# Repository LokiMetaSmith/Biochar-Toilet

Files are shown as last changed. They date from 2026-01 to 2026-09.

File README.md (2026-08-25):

# Current Status

Phase 1 (conductive heating prototype) is complete. All experiment data, firmware, schematics, PCB design files, and progress reports are in the [`Conductive Heating Prototype/`](https://github.com/PubInv/Biochar-Toilet/tree/main/Project%20Files/Conductive%20Heating%20Prototype) folder.

We're now in Phase 2: induction heating using a magnetite matrix. The shift from resistive heating matters because induction generates heat directly inside the charring cup — no exposed coils corroding in the process environment, and faster energy delivery to the material itself.

Ongoing experiment logs are in the [Progress Reports](https://github.com/PubInv/Biochar-Toilet/blob/main/Project%20Files/Progress%20Reports.md). Dedicated firmware for the dual-induction prototype is located in [`Project Files/Induction Heating Prototype/Firmware`](https://github.com/PubInv/Biochar-Toilet/tree/main/Project%20Files/Induction%20Heating%20Prototype/Firmware).

Screenshot 2025-11-21 at 6 10 39 PM

---

# Biochar Toilet

A reliable toilet that could quickly reduce human fecal matter to completely sanitary biochar would make the poorest people of the
Earth healthier. In many communities, Western-style sewage systems would be very expensive and impractical due to
geology, the lack of density in farming communities made of small land holdings, a lack of capital, and a lack of
social and political organization to dig trenches and lay pipes efficiently.

Reducing a typical human stool to biochar requires an energy input of about 600 kilojoules (see detailed analysis in referenced spreadsheet).
Even for the poorest people, the cost of this electricity is quite low---less than one US cent $0.01USD. One kilowatt hour is 3.6 MJ (megajoules).
Expensive electrical power around the world is $0.45/kWh is $0.075 USD--or less than eight cents. Even if our toilet is inefficient, it
seems possible to make a toilet whose operating cost is affordable for the poorest people, at $27.375 per year (this cost does not include
the capital costs of the toilet).

Biochar can be used as a fuel or a garden amendment. Note, however, that human stools are so small (128 grams nominally) that this is not a meaningful approach for carbon sequestration.

# Initial Design Idea

The problem of toilets is a widely researched area. Our approach may be slightly novel. We start from some assumptions:

1. Electricity is an input.
2. Complete biological safety of the end product is required.
3. We choose to temporarily ignore the capital costs of the toilet in our research.
4. Because we have to char in the absence of oxygen to prevent combustion, we can assume that we need an air-tight or pressure controlled reaction vessel.
5. A major problem in charring is to first dry the sample, and drying is primarily a problem of water transport.

We therefore conclude that our basic design will be a sealed reaction vessel with a valve that allows steam to be transported out
of the reaction chamber. We will heat the chamber contents until a desired pressure is created and then transport the water
vapor away by opening the valve. The valve will be controlled so as to avoid most gases (air) from entering the chamber.
Opening the valve will "flash" the water in the sample into steam, which will have the desirable properties of being
extremely murderous to any organisms present in the sample, and physically destructive to both plant and animal cells.
It may even physically disrupt the sample, which could be advantageous.

When the sample is sufficiently dry, we will heat it to charring temperature. When the sample is fully charred, and then cooled
and possibly wetted to avoid spontaneous combustion, the operator will be alerted that the sample is safe to remove and either combust or use as a garden amendment.

# Energy Analysis

Volunteer Nupur Bhalla working with Invention Coach Robert L. Read has produced a [Google Sheet](https://docs.google.com/spreadsheets/d/1ZwIqP0B2wM6QrpZTNiK1hNnNmIEIal7qxYdgEJz8Iog/edit?usp=sharing) representing an energy analysis of the drying and heating process.

# Heating Mechanisms

Since we will have a sealed metal reaction vessel, radio frequency (RF) heating is a possibility.
However, it is expected to become less effective as the sample dries.
We therefore intend to explore the possibility of using simple Joule resistive heating of a stainless steel vessel directly.
RF heating, however, has the advantage of heating the sample volumetrically (not requiring conduction), which may be a tremendous advantage.

# Phase 1: Conductive Heating Prototype (Complete)

Phase 1 used a pressure cooker as the reaction vessel, a hot plate controlled by an SSR, and an ESP32-based sensing system. The goal was to confirm the core architecture before committing to higher-temperature methods.

It worked. When pressure drops below ~1 PSI while temperature keeps climbing, the system correctly identifies the dry state and cuts heater power automatically. Flash decompression also checked out — opening the solenoid under pressure causes trapped water to flash to steam. A bread charring test (~110°C, 2h40m) produced a visibly charred loaf, though the dryness algorithm didn't trigger since the bread's low moisture content didn't produce a distinct enough pressure change during drying. Soot accumulation on the lid also flagged particulate management as something to design for in future iterations.

The hard limit we hit: full charring temperatures aren't safe inside a standard pressure cooker. Lawrence Kincheloe suggested placing an inner cup (heated by a silicon nitride igniter) inside the vessel so the outer shell stays cool — that idea feeds directly into Phase 2.

We also designed a custom control PCB for this phase (ESP32-H2, v0.3.0) with dual MOSFET valve drivers, dual SSR outputs, a pressure ADC, and a MAX31855 thermocouple interface. Everything is in the [`Conductive Heating Prototype/`](https://github.com/PubInv/Biochar-Toilet/tree/main/Project%20Files/Conductive%20Heating%20Prototype) folder.

# Phase 2: Induction System Development (In Progress)

We've switched from resistive heating to pulsed induction using a magnetite matrix. The magnetite sits inside the charring cup and converts the induction field directly into heat — no exposed coils, no conduction losses through the vessel wall.

Dedicated dual-induction firmware and specifications are documented in [`Project Files/Induction Heating Prototype/README.md`](https://github.com/PubInv/Biochar-Toilet/blob/main/Project%20Files/Induction%20Heating%20Prototype/README.md).

Early results from Lawrence Kincheloe and Peter are encouraging. Five grams of magnetite reached 740°F in 60 seconds; the same mass of carbon steel bearings only hit 130°F. Volume-matching the steel to the magnetite closes the gap considerably (~940°F peak), which suggests surface area and density matter more than material choice at this scale. They also charred cheese puffs at 833°F over 16 minutes in open air, with residue on the crucible cap showing evidence of partial pyrolysis.

Full experiment logs are in the [Progress Reports](https://github.com/PubInv/Biochar-Toilet/blob/main/Project%20Files/Progress%20Reports.md).

# Research Plans

The next step is pushing the induction system to actual charring temperatures — hot enough to produce biochar from organic material comparable to human stool. Work on coil geometry and magnetic field focusing is ongoing in parallel with fabrication.

Basic Biochar Toilet Design (https://github.com/user-attachments/assets/ea41856b-7663-43a1-bf12-8a3a2311aef8) 

# References

"An Experimental 13.56 MHz Radio Frequency Heating System
for Efficient Thermal Pretreatment of Wastewater Sludge",
Md. S. Ferdous, Ehssan H. Koupaie, Cigdem Eskicioglu, and Thomas Johnson*

# Volunteer Opportunities

This project is still active. If you have a background in mechanical engineering, heat engineering, or chemistry, we'd be glad to hear from you.

Reach out to Inventor Coach [Robert L. Read](https://github.com/PubInv/Biochar-Toilet/blob/main/read.robert@gmail.com) or Volunteer Coordinator [Miriam Castillo](https://www.linkedin.com/in/cstllgtrrz/). More at the [Volunteer Page](https://www.pubinv.org/volunteer/).

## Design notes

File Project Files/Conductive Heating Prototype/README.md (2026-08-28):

# Conductive Heating Prototype — Phase 1

**Biochar Toilet Project | Phase 1 Documentation** |
**Contributor:** Hardhik Pyla ([@hardhik03](https://github.com/hardhik03)) |
**Period:** November 2025 – May 2026 |
**Status:** Complete

---

## Overview

Phase 1 of the Biochar Toilet project was a proof-of-concept prototype to validate the core system architecture before advancing to higher-temperature charring methods. The goal was to build the smallest, safest system possible — one that could demonstrate:

1. Reliable pressure and temperature sensing inside a sealed reaction vessel
2. Automatic dryness detection using temperature–pressure divergence logic
3. Autonomous heater shutoff via SSR when the dry state is detected
4. Flash decompression: opening a solenoid valve under pressure to flash-boil trapped water into steam (providing mechanical sterility)

The reaction vessel was a standard pressure cooker. The heating source was a hot plate controlled by a solid-state relay (SSR). Sensing and control were handled by an ESP32-based embedded system, later migrated to a custom-designed control PCB.

---

## System Architecture

```
[Pressure Cooker] ──── [K-type Thermocouple] ───► [ESP32-H2 Control Board]
      │                                                      │
      ├──── [Analog Pressure Sensor] ───────────────────────►│
      │                                                      │
      └──── [Solenoid Valve 1] ◄──── [MOSFET Driver] ◄──────┤
                                                             │
[Hot Plate] ◄──── [SSR 1] ◄──── [NPN BJT Driver] ◄──────────┘
```

**Dryness Detection Logic:**
When pressure drops below ~1 PSI and stays there for 15 seconds (after an initial active cycle above 2 PSI), the system latches the "dry" flag and disables the heater SSR. This is based on the observed behavior that temperature rises sharply while pressure stays low once all moisture has been driven off.

**Valve Control Logic:**
The solenoid valve opens when pressure reaches 8 PSI and closes at 7 PSI (hysteresis band), releasing steam to the condenser/containment vessel.

**Temperature Control:**
A proportional controller (Kp = 0.03) targets 200°C with a 2-second PWM window. An exponential moving average (α = 0.10) smooths thermocouple readings.

---

## Hardware

| Component | Description |
|---|---|
| Reaction vessel | Standard pressure cooker |
| Microcontroller | ESP32 (breadboard) → ESP32-H2 DEVKITM-1-N4 (custom PCB) |
| Temperature sensor | K-type thermocouple + MAX31855 breakout (SPI) |
| Pressure sensor | Analog 0–100 PSI, read via ADC with voltage divider (0–5V → 0–3.3V) |
| Solenoid valve | 12V solenoid, driven by IRLB3813PBF N-channel MOSFET |
| Heater control | Solid-state relay (SSR 1), NPN BJT driver — active HIGH |
| Hot plate | External AC hot plate, switched via SSR |
| Custom PCB | Bio-Char Control Board v0.1.0 (KiCad 9, 2-layer FR4, ~$48 BOM) |

---

## Pin Configuration

The table below reflects the **working firmware pin assignments** as validated during PCB bring-up. These differ from the original KiCad schematic assignments — see the [Pin Change Notes](#pin-change-notes) section below.

| GPIO | Function | Direction | Notes |
|---|---|---|---|
| GPIO0 | MAX31855 CLK | Output | SPI clock |
| GPIO1 | MAX31855 CS | Output | SPI chip select |
| GPIO2 | MAX31855 DO | Input | SPI MISO — read-only, no MOSI needed |
| GPIO3 | Pressure Sensor ADC | Input | ADC1_CH3, 0–100 PSI via voltage divider |
| GPIO4 | SSR 1 / Heater | Output | **Active HIGH** — drives NPN BJT base to complete SSR circuit |
| GPIO5 | SSR 2 | Output | Reserved — not currently active (see firmware comments) |
| GPIO10 | Solenoid Valve 1 | Output | MOSFET (IRLB3813PBF) driven |
| GPIO11 | Solenoid Valve 2 | Output | Reserved — not currently active (see firmware comments) |

### Pin Change Notes

During PCB bring-up, the SSR control pins had to be remapped due to a conflict with the ESP32-H2's internal crystal peripheral:

- **GPIO13 and GPIO14** are internally tied to the ESP32-H2's 32 kHz RTC crystal oscillator. The original schematic routed SSR1 and SSR2 control lines to these pins. On Test 1 (05/06/2026), both SSR outputs were unresponsive — the GPIOs could not be driven as outputs while the crystal is active.
- As a Test 1 workaround, SSR1 and SSR2 were manually driven from **GPIO4 and GPIO5** (open pins on the board), confirming the BJT and SSR circuitry was otherwise functional.
- On 05/14/2026, the GPIO13 and GPIO14 traces were physically cut and jumper wires were soldered from GPIO4 → SSR1 and GPIO5 → SSR2 pads. This hardware rework makes the board match the firmware pin assignments permanently.
- The corrected routing will be incorporated into the next PCB design revision.

### Heater/SSR Logic Change

The original Arduino firmware used **active LOW** logic for the heater (GPIO4 LOW = SSR ON, sinking to GND via the SSR's internal optocoupler). The PCB design introduced an NPN BJT between the ESP32 GPIO and the SSR input, which inverts the signal:

```
GPIO4 HIGH → BJT base HIGH → collector pulls SSR input → SSR ON
GPIO4 LOW  → BJT OFF       → SSR input floating        → SSR OFF
```

The ESP-IDF firmware (`Firmware/main/main.c`) uses **active HIGH** accordingly. The `set_heater()` function drives GPIO4 HIGH to turn the heater on and LOW to turn it off.

---

## Known Errors and Issues

| # | Issue | Status | Notes |
|---|---|---|---|
| 1 | ADC non-linearity at low raw values (<350) | Mitigated | Readings below ~0.5 PSI fluctuate. DRY_PRESSURE_MAX threshold (1.0 PSI) provides sufficient headroom for reliable detection. |
| 2 | MAX31855 returns NaN on first read after power-on | Handled | ~100ms settling time required. EMA initialisation stays NaN until a valid reading arrives — no false triggers. |
| 3 | GPIO3 shared with JTAG MTDI | Known | Disconnect JTAG debugger before running in production, or remap ADC to GPIO4/5 if debugging under sustained load. |
| 4 | GPIO13/GPIO14 RTC crystal conflict — SSR pins non-functional | Resolved (05/14/2026) | Original schematic routed SSR1/SSR2 to GPIO13/GPIO14, which are internally tied to the 32 kHz RTC crystal on the ESP32-H2. Confirmed on Test 1 (05/06): both SSR outputs were unresponsive. Test 1 workaround: SSR driven manually from GPIO4/GPIO5. Permanent fix: traces to GPIO13/GPIO14 cut and jumper wires soldered to GPIO4/GPIO5 pads. Next PCB revision will correct the routing. |
| 5 | D2/D5 diode voltage drop — solenoid safety switches not opening | Resolved (05/14/2026) | 1N4148 diodes on the solenoid valve safety switch circuits had a forward voltage drop high enough to prevent the gate logic from pulling low cleanly, blocking valve operation. Bypassing the diodes confirmed the MOSFET/solenoid path was functional. D2 and D5 replaced with 1N4001 diodes; valve operation re-verified successfully. |
| 6 | Bread charring — dryness detection did not trigger | Investigated | Bread had insufficient initial moisture to produce a distinct pressure signature during drying. Detection heuristic works correctly for water-heavy samples. |

---

## Experiment Timeline

See [`Progress Reports.md`](https://github.com/PubInv/Biochar-Toilet/blob/main/Project%20Files/Progress%20Reports.md) for full dated entries. Summary:

| Date | Milestone |
|---|---|
| Nov 21, 2025 | Pressure sensor schematic designed |
| Dec 5, 2025 | Initial pressure sensor physical calibration and error testing |
| Dec 11, 2025 | Dryness detection breadboard prototype — valve, pressure, dryness logic validated |
| Jan 16, 2026 | Microcontroller + solenoid valve + SSR hardware integration |
| Feb 13, 2026 | Bread charring test with auto-shutoff — end-to-end system validated |
| Mar 5–18, 2026 | Custom Control Board PCB design (v0.1.0) — Gerbers generated |
| May 6, 2026 | PCB Board Test 1 — PSI and dry detection verified; GPIO13/14 crystal conflict and D2/D5 diode drop identified |
| May 14, 2026 | Hardware rework — GPIO13/14 traces cut, SSR lines jumpered to GPIO4/5; D2/D5 replaced with 1N4001; valve operation re-verified |

---

## Key Results

**Dryness Detection:** Successfully confirmed. When pressure falls below 1 PSI for 15 sustained seconds following an active cycle, the system correctly identifies the dry state and disables the heater.

**Flash Decompression:** Validated. Opening the solenoid valve under pressure causes water to flash to steam. However, at ~15 PSI, the valve restriction prevented instantaneous pressure drop — steam flowed continuously rather than flashing off in a single burst.

**Bread Charring Test (Feb 13, 2026):** A loaf of bread was heated inside the sealed pressure cooker at ~110°C for approximately 2 hours and 40 minutes. The loaf was visibly charred. The dryness detection algorithm did not trigger in this run (see Known Errors #5). Soot accumulation on the chamber lid was observed, raising particulate management as a future design concern.

**Key Finding — Safety Limit:** Full charring temperatures cannot be safely reached inside the pressure cooker vessel. Lawrence Kincheloe proposed an inner charring cup (heated by a silicon nitride igniter) inside the pressure cooker, keeping the outer vessel cool. This informed the transition to Phase 2 (induction heating).

---

## Firmware

Two firmware versions exist for this prototype:

| File | Platform | Notes |
|---|---|---|
| `Firmware/main/main.c` | ESP-IDF v5.x | Current — active HIGH heater logic, reserved pins commented |
| *(Arduino reference)* | Arduino IDE | Original breadboard firmware; superseded by ESP-IDF version |

The ESP-IDF firmware (`Firmware/main/main.c`) implements all three control loops simultaneously:
- Pressure-based valve hysteresis (8 PSI on, 7 PSI off)
- Dry boiler detection (sustained low-pressure latch after active cycle)
- Proportional temperature control with EMA smoothing and 2-second PWM window

To build and flash (using provided build scripts or idf.py):
```bash
# Linux / macOS (runs build, flash, monitor)
./build_firmware.sh flash monitor

# Windows
build_firmware.bat flash monitor
```

Root-level Python scripts (`dryness_monitor.py`, `valve_controller.py`, and their tests) were earlier-stage software prototypes for the same logic.

---

## PCB Design

The Bio-Char Control Board v0.1.0 is documented in detail in the main project PCB Design folder. Key specs:

- **MCU:** ESP32-H2-DEVKITM-1-N4 (RISC-V 96MHz, WiFi 802.11n, BLE 5.2)
- **Power:** 12V input → R-78E5.0-1.0 switching regulator (5V) + 2A PTC fuse + reverse-polarity protection
- **Outputs:** 2× IRLB3813PBF MOSFET solenoid drivers, 2× NPN BJT-driven SSR outputs (active HIGH)
- **Sensors:** MAX31855 SPI thermocouple, analog pressure ADC with voltage divider
- **BOM cost:** ~$48 (Mouser, March 2026)
- **Manufacturing files:** Gerbers and drill files included

---

## Conclusions and Lessons Learned

1. Temperature–pressure divergence is a reliable proxy for sample dryness and works well as an autonomous shutoff trigger.
2. Valve restriction geometry matters significantly for flash decompression — a lower-restriction valve is needed for true instantaneous pressure drop.
3. Low-moisture samples (like dry bread) do not produce a clear pressure signature during drying, requiring either a different detection heuristic or moisture pre-conditioning.
4. Soot and particulate management inside the reaction vessel needs to be designed for from the start in future iterations.
5. Charring temperatures (>400°C) cannot be safely achieved in the pressure cooker configuration — an inner heated vessel is necessary.
6. The custom PCB successfully consolidates all sensing and control onto a single board, validating the embedded architecture for future phases.
7. Crystal-reserved GPIOs on the ESP32-H2 (GPIO13, GPIO14 for the 32 kHz RTC crystal) must be identified and avoided during schematic design — they appear usable in simulation but are unresponsive as outputs on hardware while the crystal is active.
8. 1N4148 diodes are inadequate for solenoid valve safety switch circuits at the currents involved — the forward voltage drop prevents clean gate logic switching. 1N4001 is the correct replacement.

---

## Files in This Folder

```
Conductive Heating Prototype/
├── README.md                        ← This file
└── Firmware/
    ├── CMakeLists.txt               ← ESP-IDF top-level build file
    └── main/
        ├── CMakeLists.txt           ← Component registration
        └── main.c                   ← ESP-IDF integrated control firmware
```

Hardware files (schematics, PCB design, test videos) are in the corresponding subfolders of the main project directory and cross-referenced above.

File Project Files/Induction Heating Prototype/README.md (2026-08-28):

# Phase 2: Dual Induction Heating Prototype

**ESP32-H2 Microcontroller Firmware & Hardware Architecture for Dual Induction Pyrolysis System**

---

## 📋 System Overview

The Phase 2 Dual Induction Heating Prototype upgrades the biochar reactor architecture from resistive heating to a dual-induction heating assembly:

1. **Main Vessel Induction Coil:** Hand-formed hollow copper coil isolated with high-temperature Kapton tape, surrounding the inner vessel inside the modified Hawkins 12L pressure cooker. Driven by an 1800W ZVS DC induction heater via SSR 1 (GPIO4).
2. **Catalytic Converter Induction Heater:** Dedicated secondary induction heater surrounding the external catalytic converter zone. Driven via SSR 2 (GPIO5) to maintain continuous high temperature (800°C+) during processing for syngas cracking and odor mitigation.

---

## 🔧 System Specifications

- **Microcontroller:** Espressif ESP32-H2-DEVKITM-1-N4 (RISC-V, 96MHz)
- **Power Architecture:** 48V LiFePO4 battery bank / Mean Well RSP-2400-48 DC PSU with ZVS induction drivers
- **Pressure Sensing:** 0–15 PSI range (0–5V analog output, mapped to ADC1_CH2 / GPIO3 via 0-3.3V divider)
- **Valve Control:** Solenoid Valve 1 (MOSFET-driven, GPIO10) for pressure relief and steam swing drying
- **Recirculating Pump:** Optional high-current MOSFET driver on GPIO11 (Solenoid 2 channel) for heat exchanger loop cooling
- **Flush Button:** Manual push switch on GPIO12 (Active LOW with internal pull-up) to initiate biochar cycle (30-min auto-timeout) and reset emergency trip via 3s long-press
- **Status LED:** Onboard WS2812 RGB LED on GPIO8 (Green=IDLE/Ready, Orange=Active Cycle, Blue=Dry Latched/Complete, Flashing Red=Emergency Trip)
- **Thermocouple Interface:** MAX31855 K-type breakout via SPI (GPIO0 CLK, GPIO1 CS, GPIO2 MISO)

---

## 📂 Firmware Layout (`Project Files/Induction Heating Prototype/Firmware`)

```
Firmware/
├── CMakeLists.txt         # Root ESP-IDF CMake configuration (project: biochar_induction_firmware)
├── build_firmware.sh      # Linux/macOS build script (auto-fetches ESP-IDF v5.2.1 if needed)
├── build_firmware.bat     # Windows build script
├── .gitignore             # Excludes build output
└── main/
    ├── CMakeLists.txt     # Main component CMake configuration
    └── main.c             # System control loop, ADC calibration, dual heater logic & safety checks
```

---

## 🚀 Building & Flashing Firmware

Navigate to `Project Files/Induction Heating Prototype/Firmware` and run:

**Linux / macOS:**
```bash
./build_firmware.sh
```

**Windows:**
```bat
build_firmware.bat
```

The build scripts clear cached build artifacts, set the target to `esp32h2`, and build the binary via `idf.py build`.

### Passing Additional Targets (Flash & Monitor)

You can pass extra `idf.py` commands (such as `flash`, `monitor`, or `flash monitor`) directly as arguments to the build script:

**Linux / macOS:**
```bash
./build_firmware.sh flash monitor
```

**Windows:**
```bat
build_firmware.bat flash monitor
```

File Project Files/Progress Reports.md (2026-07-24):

## **[07/24/2026]**

**Phase 3 Ideation – Physical System Frame Design**

Worked in FreeCAD 1.1 to pull together Hawkins 12L Pressure Pot assembly components and to start initial system frame rigging design using 20mm x 40mm extruded aluminum and compatible hardware. Uploaded current FCStd file status into the Public Invention/Biochar-Toilet/Project Files/CAD Files folder as "Frame for Assembly_v2.FCStd". Once all essential components are uploaded, and component assembly layout has been established, specific joint bracket hardware will be added to a parts list to create a Frame BOM, and custom brackets will be designed and sent to fabrication as-needed, with details uploaded to Frame BOM. 

## **[07/03/2026]**

**Phase 3 Ideation – High-Temperature H2S Scrubbing Refinement**

Refined the Phase 3 sulfur mitigation strategy by proposing a high-temperature Silicon Carbide (SiC) and Magnetite cartridge at the bottom of the reaction vessel. This cartridge serves as the final high-temperature "choke point" (800°C+) for downdraft syngas, maximizing H2S removal efficiency before the gas reaches the solenoid valve and external heat recovery hardware. This addition completes the three-tier sulfur defense architecture: in-situ fixation (biochar), peak-temp scrubbing (bottom cartridge), and low-temp polishing (iron sponge). Updates were applied to the [Syngas Processing Memo](Memos/Syngas_Processing_Memo.md) and `DESIGN_IDEAS.md`.

## **[07/01/2026]**

**Phase 3 Ideation – Syngas Processing and Ceramic Liners**

Documented advanced Phase 3 concepts regarding the management of syngas exhaust and modular ceramic liner assemblies. A new engineering memo was created detailing the highly practical lean combustion pathway for oxidizing Syngas into CO₂, and exploring sulfur mitigation strategies directly within the biochar mixture using in-situ fixation and Iron Sponge dry scrubbers. Furthermore, design guidelines for "leaky" modular ceramic assemblies with slip-fit baffles were established to prevent thermal shear failure in the heat exchanger. The complete analysis is recorded in the [Syngas Processing Memo](Memos/Syngas_Processing_Memo.md) and linked in `DESIGN_IDEAS.md`.

## **[06/17/2026]**

**Post presentation notes on live demo**

Firmware needed a slight update to assign  
main.c file: #define PIN_ADC_PRESSURE ADC_CHANNEL_3 // GPIO3, should be  ADC_CHANNEL_2

The DC SSR and battery combo was controlled with a simple momentary switch, which worked well for testing the induction heater. It was found that the coils were shorting out, which created a large spark and irratic performance of the heater. It is assumed that the spark created an inductive spike which may have blown a hole in the capacitors, which may be self healing. Normal operation resumed after some time, however this may be due to other factors. 

The water became steaming hot, and we need to integrate in a radiator into the system. 

High water content fruit, such as raspberries, do not produce much char and additonally do not make as much noxious odors. 

The hot plate bio char pot developed a stuck seal, such that it wouldn't pressurize. It's assumed that the gasket became fouled or not enough moisture is present to engage the pop up locking valve pin. This failue mechanism is not on the oval pot, which uses positive pressure on the entire lid to prevent inadvertant lid removal. 

We were able to biochar or induce pyrolysis with the hot plate version, it took about 2 hours to stop seeing significant steam/smoke/vapor from the leaking seal. 

We demonstrated that magnetic seperation worked with the magnetite mixed sample, using a harddrive magnet and a glass test tube. An electromagnet or a rotating magnet bar would be ideal for this application in the future. 

We should have created a fresh batch of tested mix, our existing mix may not be performing optimally. We also need to run more tests with water and fully drying times.

## **[05/14/2026]**

**PCB Control Board – Trace Rework and Hardware Fixes**

Following Test 1 findings, Hardhik performed hardware rework on the Bio-Char Control Board (v0.1.0) to resolve the two issues identified on 05/06:

GPIO13 and GPIO14 traces to the SSR control lines were physically cut on the PCB. Jumper wires were soldered from GPIO4 and GPIO5 directly to the SSR1 and SSR2 pads respectively, bypassing the original routing. This brings the hardware into alignment with the current firmware pin assignments. The trace cut and remap will be incorporated into the next PCB design revision.

Diodes D2 and D5 (1N4148) on the solenoid valve safety switch circuits were desoldered and replaced with 1N4001 diodes. The 1N4148's forward voltage drop under the switch current was high enough to prevent the safety switches from pulling the gate logic low cleanly, keeping the solenoid valves from opening. The 1N4001's lower drop at higher currents resolved this. Valve operation was re-verified after the swap and both solenoids opened and closed correctly.

These changes are hardware-only, no firmware modifications were required.

**PCB Control Board – Initial Testing (Test 1)**

Hardhik conducted the first round of physical tests on the assembled Bio-Char Control Board (v0.1.0). The test session covered four areas of the board's integrated control firmware, but also uncovered two hardware issues that required rework.

PSI readings from the analog pressure sensor were confirmed correct across the expected range. ADC-to-PSI calibration constants (ADC_ZERO = 320, ADC_FULL = 3008) were validated against a reference gauge. The dry-boiler detection logic also worked as expected — after a sustained pressure drop below 1 PSI for 15 seconds following an active cycle, the dryLatched flag triggered and the heater SSR was disabled correctly. A full-system Serial readout at 115200 baud was recorded showing pressure, valve, heater, and temperature simultaneously.

Two hardware faults were found:

**SSR pins non-functional (GPIO13/GPIO14 crystal conflict):** GPIO13 and GPIO14 on the ESP32-H2 are internally tied to the 32 kHz RTC crystal oscillator and cannot be used as general-purpose outputs. The original schematic routed the SSR1 and SSR2 control lines to these pins. As a workaround for Test 1, the SSR lines were driven from GPIO4 and GPIO5 (open pins), confirming the SSR and BJT circuitry itself works correctly once a valid GPIO is used. A permanent trace rework was scheduled.

**Solenoid valve safety switches not opening (D2, D5 diode voltage drop):** Diodes D2 and D5 (1N4148) on the solenoid valve safety switch circuits had a higher-than-expected forward voltage drop under the switch current, which prevented the gate logic from pulling low cleanly and kept the valves from opening. The valves were tested by bypassing the diodes to confirm the MOSFET and solenoid circuits were otherwise functional. Replacement with 1N4001 diodes was scheduled.

Valve hysteresis (8 PSI open, 7 PSI close) was verified using the GPIO4/GPIO5 workaround after identifying the GPIO13/GPIO14 issue.

## **[04/24/2026]**
Lawrence and Peter ran a series of experiments with different amounts of material that we want to use for induction heating. 
The temperature measurements are located in [Induction experimental data.md](https://github.com/PubInv/Biochar-Toilet/blob/main/Induction experimental data.md)
Interestng results were that we didn't hit the curie temperature of the carbon steel, as evident by the thermal readings and the presence of a magnetic field. Based on
color charts for steel and our measurements, we estimate we got up between 900-1000 degrees F for the pure ball bearing. 

Quick Observations
The Magnetite Advantage: At 5 grams, the Magnetite is significantly more efficient at converting the induction field to heat compared to the same mass of Carbon Steel bearings (reaching 740°F vs 130°F in 60 seconds).

Volume vs. Mass: The Carbon Steel only starts to compete in peak temperature (940°F) when the volume is matched to the Magnetite, suggesting density and surface area are playing a massive role here. 
It is believed that this is due to eddie currents, which seem to favor lengh wise induced current when the material is making good electrical contact. 

The "Mixed" Thermal Inertia: The mixture shows a much more gradual and staggered climb, likely due to the Bentonite acting as a thermal buffer or insulator between the active heating elements.
Further adjustments to the mix will need to be determined to balance thermal heat transfer, rapid heating, and options for agitation. 

Peter will drill out the holes for the induction heater next week, and we are continuing to debug issues with the higher power induction coil. 
Right now we suspect the issue may be the spacing on the coils (currently 10-30mm), but it's interesting to note that coil geometry has a large effect on heating potential. 
We may need to accelerate our understanding of coil geometry and options for focusing the magnetic field towards the center of the crucible.

## **[03/27/2026]**
Lawrence and Peter ran an experiment attempting to char cheese puffs. The cheese puffs are about 8mm in diameter, 
and there were about 6 of them in the crucible, moistened with water and coated in mostly magnetite with some kitty litter.
The induction coil system had been running for about 5 minutes when the mixture began smoking. The max temperature attained was 833F before the team put a cap on the 
system at the 9 minute marker (an arbitrary amount of time).

Once the system had cooled to safe handling temperature, the team opened the lid to discover the results were good. All but one of the cheese puffs all charred all 
the way through. This experiment was conducted in the open air (oxygen-rich) so pyrolysis was not as efficient, but there WAS evidence of some pyrolysis happeneing, 
due to the residue on the crucible cap.

The total powered time of this experiment was about 16 minutes. 

## **[03/20/2026]**
Lawrence and Peter had identified and (Lawrence) updated the project BOM with the bulkhead fittings and hardware required for the induction coil 
system to insulate the energized copper from the aluminum pot, as well as to seal the fitting and lock the insulated sleeve in place using a 
furrel nut and insolating washer. They also identified 440 stainless steel shot 2mm as being an excellent starting point for mixing with
the magnetite.

Peter had digitized the bounding box of the induction module (for clearance) and the model of the 1" air line's bulkhead fitting;
he also imported STEP files of the PSU and T-Pipe fitting. The purpose for this is to create proper mounting systems contining the 
components to make a solid, safe, transportable unit for demonstration and experimentation.

## **[03/18/2026]**

**Bio-Char Control Board PCB – v0.1.0 Design Complete**

Hardhik completed the design and manufacturing file generation for the Bio-Char Control Board v0.1.0, an ESP32-H2-based industrial control PCB purpose-built for the bio-char production system. The design work ran from March 5 through March 18, spanning 14 KiCad revision checkpoints.

The board integrates the full sensor and control stack onto a single 2-layer FR4 PCB:
- **Microcontroller:** ESP32-H2-DEVKITM-1-N4 (RISC-V 96MHz, WiFi 802.11n, BLE 5.2, Thread/Zigbee capable)
- **Power management:** 12V input → R-78E5.0-1.0 switching regulator (5V, 95% efficiency) with 2A PTC resettable fuse and reverse-polarity protection diode
- **High-power outputs:** 2× IRLB3813PBF N-channel MOSFETs for solenoid valve control (upgraded from IRLB8721PBF for lower Rds(on) of 2.3mΩ and higher current headroom); 2× NPN transistor-driven SSR outputs
- **Sensors:** MAX31855 K-type thermocouple breakout (SPI, −200°C to +700°C) and analog pressure sensor input with voltage divider (0–5V → 0–3.3V)
- **Safety:** Flyback diodes on all inductive loads, manual override switches for both solenoids, Phoenix Contact screw terminals throughout

The complete BOM was finalized and verified against Mouser Electronics pricing: 40 components across 18 types at a total cost of ~$48 (as of March 2026). Gerber files and NC drill files were generated and are ready for fabrication at JLCPCB, PCBWay, or OSH Park using standard 2-layer, 1.6mm FR4, 1oz copper settings.

## **[03/06/2026]**
Lawrence and Peter were able to fill a crucible with 100% magnetite and a cup of water, then using only the induction coil 
system, was able to evaporate all of the water in less than 8 minutes, starting with the sample at room temperature.
Next steps towards biochar include testing different ratios of kitty litter (bentonite), magnetite, and mild steel shot to not only
evaporate water quickly, but to char an organic sample. 
Data will be collected then analyzed via spreadsheet graph comparison.

## **[02/13/2026]**

**Dryness Detection + Auto Shutoff – Bread Charring Test**

Hardhik ran a combined dryness-detection and automatic shutoff test using bread as the organic sample. The system consisted of the microcontroller connected to a solenoid valve and an SSR-controlled hot plate. Key hardware integrations documented in this session included the SSR wired to the hot plate and the microcontroller-to-valve connection.

The bread was placed in the charring vessel and the system was powered on. The hot plate heated the sample while the pressure sensor monitored internal pressure. The dryness detection logic — which tracks a sustained low-pressure window after an initial active cycle — successfully identified when the material had dried sufficiently and triggered the auto shutoff, cutting power to the hot plate via the SSR.

The charred bread result showed visible and complete charring throughout the sample. This confirmed that the integrated dryness detection and automatic shutoff pipeline works end-to-end: the system can autonomously stop heating once the organic material is processed, without requiring manual intervention.

Video evidence of the test process and the final charred bread result were captured for documentation.

## **[01/16/2026]**

**Dryness Detection + Valve Auto Shutoff – Hardware Integration**

Hardhik integrated the microcontroller, solenoid valve, and SSR into a working prototype for the dryness detection and auto-shutoff system. Prior breadboard work was assembled into a more connected configuration, with the valve and SSR now driven directly by the ESP32 GPIO outputs.

Multiple video recordings were captured documenting the valve actuation behavior, the sensor feedback loop, and overall system operation. The system demonstrated the ability to open and close the solenoid valve based on pressure thresholds, while independently managing the heater SSR through the temperature control loop — operating both control loops concurrently without interference.

This session established the core firmware architecture (pressure-based valve hysteresis + dry detection + proportional temperature control) that later became the basis for the PCB firmware.

## **[12/11/2025]**
**Dryness Detection – Breadboard Prototype**

Hardhik built and tested an initial breadboard prototype for dryness detection. The circuit connected a pressure sensor and solenoid valve to an ESP32 microcontroller to test the concept of detecting when a heating cycle has driven off all moisture from a sample.

Key tests conducted in this session:

- **Dryness Detection:** The system successfully distinguished between an "active" pressurized state and a "dry" low-pressure state, validating the logic of using pressure as a proxy for remaining moisture in the system.
- **Pressure Sensor Check:** The sensor readings were verified on the breadboard against known pressure values.
- **Valve Turning ON / OFF:** The solenoid valve was confirmed to open and close correctly under GPIO control at the expected pressure thresholds.

The breadboard circuit provided confidence in the sensing and actuation approach before moving toward a more permanent hardware integration.

## **[12/05/2025]**
**Pressure Sensor – Initial Physical Testing**

Following the pressure sensor schematic work (Nov 21), Hardhik conducted the first physical pressure sensor tests. Two recordings were captured: one showing successful pressure sensor calibration against a reference, and one documenting a sensor error condition (likely an out-of-range or wiring issue) to characterize failure modes.

The calibration session established the ADC-to-PSI mapping that would later be formalized in firmware (ADC_ZERO ≈ 320, ADC_FULL ≈ 3008 for 0–100 PSI full-scale). Understanding the error behavior of the sensor was an important step for designing reliable dryness detection logic in subsequent firmware iterations.

## **[11/21/2025]**
**Pressure Sensor – Schematic Design**

Hardhik designed the initial pressure sensor schematic for the Phase 1 prototype. The schematic documents the sensor wiring, voltage divider configuration (0–5V → 0–3.3V for ESP32 ADC compatibility), and connector pinout. This served as the hardware reference for subsequent physical testing and was later incorporated directly into the Control Board PCB design.

## **[11/07/2025]**
**Flash System Prototype - Test 1**

On Nov.7th an initial prototype was tested. This consisted of a pressure cooker containing a cup of water,
with a thermocouple added and a hose connected to an electronic valve, leading to a condenser.

This experiment was largely confirmatory of our approach, but we learned certain things:
1. At high power and about 15 psi, the steam does not "flash" off. When the valve is opened, the
steam escapes, but it keeps flowing. Our valve apparently produces so much restriction that the
pressure does not drop quickly (though it does drop, but remains positive).
2. The temperature did rise DRASTICALLY when the water dried up. Our theory that we can detect this by the time that the pressure ceases to rise and the temperature does rise is well established.
3. A small amount of steam leaked through my high-temperature epoxy around the thermocouple.

So in principle, this was a successful test.

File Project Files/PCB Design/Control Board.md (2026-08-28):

# Bio-Char Control Board v0.3.0

**ESP32-H2 Based Industrial Control System for Bio-Char Production**

---

## 📋 Overview

The Bio-Char Control Board is an industrial-grade PCB designed to control and monitor bio-char production processes. It features WiFi/Bluetooth connectivity, multi-voltage power management, high-power output control, and sensor interfaces.

### Key Features
- **ESP32-H2 Microcontroller** - WiFi 802.11n + Bluetooth 5.2
- **Multi-Voltage Power System** - 12V input, regulated 5V and 3.3V rails
- **High-Power Output Control** - 2× Solenoid valves / High Current MOSFET outputs, 2× SSR outputs
- **Sensor Interfaces** - K-type thermocouple, analog pressure sensor
- **Manual Override** - Physical switches for safety
- **Professional Design** - 2-layer PCB, through-hole components for easy assembly

---

## 🔧 Hardware Specifications

### Power Supply
- **Input:** 12V DC (via Phoenix terminal block)
- **5V Rail:** R-78E5.0-1.0 switching regulator (1A, 95% efficiency)
- **3.3V Rail:** ESP32-H2 internal LDO
- **Protection:** 2A PTC resettable fuse, reverse polarity protection

### Microcontroller
- **IC:** Espressif ESP32-H2-DEVKITM-1-N4
- **Connectivity:** WiFi 802.11b/g/n (2.4GHz), BLE 5.2, Thread/Zigbee capable
- **Flash:** 4MB
- **RAM:** 272KB SRAM
- **Processor:** RISC-V 96MHz

### Output Control
- **Solenoid Valves / High Current Outputs:** 2× IRLB3813PBF N-channel MOSFETs (30V, 100A, 2.3mΩ)
- **SSR Control:** 2× NPN transistor drivers (2N3904)
- **Protection:** Flyback diodes on all inductive loads

### Sensor Interfaces
- **Thermocouple:** MAX31855 breakout module (K-type, -200°C to +700°C, SPI)
- **Pressure Sensor:** Analog input with voltage divider (0-5V → 0-3.3V)

### Connectors
- **Phoenix Contact Terminals:** 5.08mm pitch, 90° horizontal
  - 1× 3-position (pressure sensor)
  - 5× 2-position (power input, solenoids, SSRs)
- **Pin Headers:** 2.54mm pitch
  - 1× 8-pin (general I/O)
  - 1× 6-pin (MAX31855 interface)

---

## 📦 Bill of Materials (BOM) & System Variants

### Control Board PCB Assembly BOM

**Complete BOM available:** [`Bio_Char_BOM_Mouser_FINAL.xlsx`](Bio_Char_BOM_Mouser_FINAL.xlsx)

#### BOM Summary
- **Total Component Types:** 18
- **Total Components:** 40 items
- **Total Cost:** $48.12 (verified Mouser pricing as of March 2026)
- **Supplier:** Mouser Electronics

#### Key PCB Components

| Category | Component | Part Number | Qty | Unit Price |
|---|---|---|-----|---|
| **Microcontroller** | ESP32-H2-DEVKITM-1-N4 | 356-ESP32H2DKITM1-N4 | 1 | $9.38 |
| **Power** | R-78E5.0-1.0 Regulator | 919-R-78E5.0-1.0 | 1 | $3.97 |
| **Power** | Polyfuse 2A | 530-0ZRN0200FF1E | 1 | $0.42 |
| **MOSFETs** | IRLB3813PBF | 942-IRLB3813PBF | 2 | $2.16 |
| **Transistors** | 2N3904BU | 512-2N3904BU | 2 | $0.28 |
| **Diodes** | 1N4001RLG | 863-1N4001RLG | 2 | $0.13 |
| **Diodes** | 1N4148 | 512-1N4148 | 2 | $0.10 |
| **Diodes** | 1N5819RLG | 863-1N5819RLG | 1 | $0.39 |
| **Resistors** | 1kΩ 1/4W | 603-CFR-25JR-521K | 6 | $0.18 |
| **Resistors** | 100kΩ 1/4W | 603-CFR-25JB-52-100K | 4 | $0.18 |
| **Resistors** | 10kΩ 1/4W | 603-CFR-25JB-52-10K | 2 | $0.10 |
| **Resistors** | 22kΩ 1/4W | 603-CFR-25JB-52-22K | 2 | $0.10 |
| **Capacitors** | 100nF Ceramic | 80-C322C104K5R5TA | 3 | $0.87 |
| **Capacitors** | 47µF 25V Electrolytic | 598-476CKH025M | 2 | $0.21 |
| **Terminals** | Phoenix 2-pos 5.08mm | 651-1715721 | 5 | $1.30 |
| **Terminals** | Phoenix 3-pos 5.08mm | 651-1715734 | 1 | $1.66 |
| **Headers** | Pin Headers 2.54mm | 649-1012937990801BLF | 2 | $0.14 |
| **Modules** | MAX31855 Breakout | 485-269 | 1 | $14.95 |

**Note:** MOSFET upgrade from IRLB8721PBF to IRLB3813PBF provides better performance (lower Rds(on), higher current rating).

---

### System Peripheral BOM: Conductive vs. Induction Variants

The control board connects to peripheral hardware specific to each prototype generation:

#### Phase 1: Conductive Heating System Peripherals
| Subsystem | Component | Specifications | Connection |
|---|---|---|---|
| **Heater** | Single Resistive Hot Plate | 120V / 1000W Joule element | SSR 1 Output (GPIO4) |
| **Pressure Sensor** | 0–100 PSI Transducer | 0.5–4.5V output | ADC Input (GPIO3) via divider |
| **Valves** | 1× Solenoid Valve | U.S. Solid 1" SS 12V DC | Solenoid 1 MOSFET (GPIO10) |
| **Temperature** | K-Type Thermocouple | Single sheath in vessel wall | MAX31855 SPI (GPIO0/1/2) |

#### Phase 2: Dual Induction Heating System Peripherals
| Subsystem | Component | Specifications | Connection |
|---|---|---|---|
| **Main Heater** | 1800W ZVS Induction Unit | 12V–48V DC, hollow copper vessel coil | SSR 1 Output (GPIO4) |
| **Catalyst Heater** | ZVS Induction Unit | 12V–48V DC, catalytic converter zone | SSR 2 Output (GPIO5) |
| **Pressure Sensor** | 0–15 PSI Transducer | 0–5V output (high resolution) | ADC Input (GPIO3) via divider |
| **Valves** | 1× Solenoid Valve | U.S. Solid 1" SS 12V DC | Solenoid 1 MOSFET (GPIO10) |
| **Fluid Cooling** | Recirculating Pump | 110V / 12V DC water circulator | Solenoid 2 MOSFET (GPIO11) |
| **Temperature** | K-Type Thermocouple | Single sheath in vessel side wall | MAX31855 SPI (GPIO0/1/2) |

---

## 📐 PCB Specifications

### Physical Dimensions
- **Board Size:** TBD (verify in KiCad)
- **Layers:** 2 (Top + Bottom copper)
- **Thickness:** 1.6mm standard FR4
- **Copper Weight:** 1oz (35µm)

### Design Rules
- **Minimum Track Width:** 0.25mm (signal), 2.0mm (power)
- **Minimum Clearance:** 0.25mm
- **Via Size:** 0.6mm drill, 1.0mm pad (standard)
- **Surface Finish:** HASL or ENIG recommended

### Manufacturing Files
All necessary manufacturing files are included in this repository:
- **Gerber Files/** - Complete gerber set for PCB fabrication
- **Drill Files/** - NC drill files for hole placement

---

## 🔌 Pin Assignments & Firmware Variants

### 1. Original Conductive Heating Firmware Variant (`Project Files/Conductive Heating Prototype/Firmware`)

| GPIO | Function | Hardware Connection | Notes |
|---|---|---|---|
| GPIO0 | MAX31855 CLK | SPI Clock | Thermocouple SPI |
| GPIO1 | MAX31855 CS | SPI Chip Select | Thermocouple SPI |
| GPIO2 | MAX31855 DO | SPI Data Out (MISO) | Thermocouple SPI |
| GPIO3 | ADC Pressure | ADC1_CH2 Input | 0–100 PSI Sensor via voltage divider |
| GPIO4 | SSR 1 Control | Q2 base → SSR 1 | Main Resistance Hot Plate |
| GPIO5 | SSR 2 Control | Q5 base → SSR 2 | Reserved / Secondary |
| GPIO10 | Solenoid 1 Control | Q1 MOSFET Driver | Main Vent Solenoid Valve 1 |
| GPIO11 | Solenoid 2 Control | Q3 MOSFET Driver | Reserved / Valve 2 |

### 2. Dual Induction Heating Firmware Variant (`Project Files/Induction Heating Prototype/Firmware`)

| GPIO | Function | Hardware Connection | Notes |
|---|---|---|---|
| GPIO0 | MAX31855 CLK | SPI Clock | Thermocouple SPI |
| GPIO1 | MAX31855 CS | SPI Chip Select | Thermocouple SPI |
| GPIO2 | MAX31855 DO | SPI Data Out (MISO) | Thermocouple SPI |
| GPIO3 | ADC Pressure | ADC1_CH2 Input | 0–15 PSI (0–5V) Sensor via voltage divider |
| GPIO4 | Main Coil Heater | Q2 base → SSR 1 | Main Vessel Induction Coil (PWM controlled) |
| GPIO5 | Catalyst Heater | Q5 base → SSR 2 | Catalytic Converter Induction Heater (Active during cycle) |
| GPIO8 | Status LED Driver | WS2812 RGB LED | Onboard RGB LED indicator (Green=IDLE, Orange=ACTIVE, Blue=DRY, Red Flashing=TRIP) |
| GPIO10 | Solenoid 1 Control | Q1 MOSFET Driver | Main Vent Solenoid Valve 1 |
| GPIO11 | Recirculating Pump | Q3 MOSFET Driver | Water/Fluid Recirculating Pump (Feature flagged) |
| GPIO12 | Flush Button Input | Manual Push Switch | Active LOW input (internal pull-up) — short-press starts cycle, 3s long-press resets emergency trip |

*Note: GPIO8/9 are internally tied to the ESP32-H2 32 MHz crystal oscillator and cannot be used for general I/O. GPIO14/15 are reserved for the 32 kHz RTC crystal.*

---

## ⚡ Power Distribution

### Power Tree
```
12V Input (J1)
  │
  ├─[F1: Polyfuse 2A]─┬─[D1: 1N4001RLG]─┬── +12V Rail
  │                   │                  │   (Solenoids, Pumps, SSR drivers)
  │                   │                  │
  │                   │                  └── [U3: R-78E5.0-1.0 Input] ──> 5V Rail
  │                   └─[C6: 47µF 25V]
  │
  └── ESP32 LDO ───> 3.3V Rail (Internal peripherals)
```

### Current Budget
- **12V Rail:** ~3-4A max (solenoids + regulator input)
- **5V Rail:** ~1A max (ESP32 + MAX31855)
- **3.3V Rail:** ~500mA max (ESP32 internal)

---

## 🛠️ Assembly Instructions

### Component Placement Order
1. **Passive Components First:** Resistors, diodes, capacitors
2. **IC Sockets (if used):** For U1, U3 (optional)
3. **Power Components:** F1, D1, U3, Q1, Q3
4. **Signal Components:** Q2, Q5, remaining passives
5. **Connectors:** Phoenix terminals, pin headers
6. **Modules Last:** ESP32-H2, MAX31855 (after testing power rails)

### Soldering Tips
- Use temperature-controlled soldering iron (350°C)
- Start with low-profile components
- Double-check polarized components (diodes, electrolytic caps)
- Test power rails before installing ESP32 and MAX31855

### Testing Procedure
1. **Visual Inspection:** Check for solder bridges, cold joints
2. **Power Test:** Apply 12V, verify 5V output (no load)
3. **Current Test:** Measure idle current (<50mA expected)
4. **ESP32 Test:** Upload basic blink sketch
5. **Sensor Test:** Read MAX31855 and pressure sensor
6. **Output Test:** Test MOSFET switching with load

---

## 📂 Repository Structure

```
PCB Design/
├── Bio_Char_BOM_Mouser_FINAL.xlsx    # Bill of Materials
├── Control Board.kicad_sch            # Schematic
├── Control Board.kicad_pcb            # PCB Layout
├── Control Board.kicad_pro            # Project File
├── Control Board.kicad_prl            # Local Settings
├── Control Board.md                   # This file
├── PCB_v0.4.0_Induction_Revision_Plan.md # Hardware Roadmap for v0.4.0
├── Gerber Files/                      # Manufacturing Files
│   ├── F_Cu.gbr                       # Top Copper
│   ├── B_Cu.gbr                       # Bottom Copper
│   └── ...                            # Additional layers
└── Drill Files/                       # NC Drill Files
```

---

## 🚀 Getting Started

### Prerequisites
- KiCad 9.0 or later
- Basic understanding of electronics
- Soldering equipment
- 12V DC power supply

### Ordering PCBs
1. Download gerber files from `Gerber Files/` folder
2. Upload to PCB manufacturer (JLCPCB, PCBWay, OSH Park, etc.)
3. Recommended settings:
   - Layers: 2
   - Thickness: 1.6mm
   - Copper: 1oz
   - Surface Finish: HASL or ENIG
   - Soldermask: Green (or your preference)

### Ordering Components
1. Open `Bio_Char_BOM_Mouser_FINAL.xlsx`
2. All Mouser part numbers are verified and ready to order
3. Total cost: ~$48 (as of March 2026)
4. Order from: [Mouser Electronics](https://www.mouser.com)

---

## 🔍 Design Decisions

### Why ESP32-H2?
- Native WiFi and Bluetooth connectivity
- Thread/Zigbee support for future smart home integration
- Adequate GPIO for all control and sensing needs
- Low power consumption
- Active community support

### Why Through-Hole Components?
- Easier hand assembly for prototypes
- Better for educational purposes
- More robust mechanical connections
- Easier to debug and repair
- Suitable for industrial environments

### Why IRLB3813PBF MOSFETs?
- Upgrade from original IRLB8721PBF
- Lower Rds(on) (2.3mΩ vs 8.7mΩ) = less heat
- Higher current rating (100A vs 62A) = more headroom
- Logic-level gate (works with 3.3V ESP32)
- Better availability

---

## ⚠️ Safety Considerations

### Electrical Safety
- **Input Fuse:** PTC resettable fuse provides overcurrent protection
- **Reverse Polarity:** D1 protects against reverse voltage
- **Flyback Protection:** Diodes on all inductive loads
- **Isolation:** Keep 12V and 3.3V circuits separated

### Operating Conditions
- **Temperature Range:** 0°C to 60°C ambient
- **Humidity:** <85% RH (non-condensing)
- **Ventilation:** Ensure adequate airflow around regulator

### Installation
- Use proper gauge wire for 12V input (18 AWG minimum)
- Secure all screw terminals tightly
- Mount board in protective enclosure
- Keep away from moisture and extreme temperatures

---

## 📝 Version History

### v0.3.0 (March 2026) - Current
- Complete PCB layout with routing
- Verified BOM with Mouser pricing
- Manufacturing files (Gerbers + Drills) generated
- MOSFET upgrade to IRLB3813PBF
- Dual-variant documentation (Conductive vs Induction)

### v0.2.0
- Schematic refinement
- Component selection and footprint assignment

### v0.1.0
- Initial schematic design
- Basic architecture

---

## 👤 Author

**hardhik03**
- GitHub: [@hardhik03](https://github.com/hardhik03)

---

**Last Updated:** March 18, 2026
**KiCad Version:** 9.0.7
**Board Revision:** v0.3.0

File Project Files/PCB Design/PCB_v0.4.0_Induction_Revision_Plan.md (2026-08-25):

# Bio-Char Control Board v0.4.0 — Hardware Revision Roadmap

**Dedicated Hardware Modifications for Phase 2/3 Dual Induction & Closed-Loop Control**

---

## 📋 Revision Objectives

The current Control Board v0.3.0 supports single-thermocouple SPI sensing and basic dual SSR switching. To support dual independent temperature control (vessel + catalytic converter) and closed-loop liquid recirculation, Control Board v0.4.0 will introduce dedicated hardware routing modifications.

---

## 🛠️ Required Hardware Changes

### 1. Dual Thermocouple SPI Interface (Catalyst & Vessel Sensing)
- **New Feature:** Second MAX31855 SPI Chip Select line on **GPIO6**.
- **Bus Sharing:** Shares SPI CLK (**GPIO0**) and SPI MISO (**GPIO2**) with the primary vessel MAX31855 breakout.
- **Pin Assignment:**
  - `GPIO0`: MAX31855 SPI CLK (Shared)
  - `GPIO1`: MAX31855 CS1 (Vessel Thermocouple)
  - `GPIO2`: MAX31855 MISO (Shared)
  - `GPIO6`: MAX31855 CS2 (Catalytic Converter Thermocouple)

### 2. High-Current Recirculating Pump MOSFET Driver
- **Upgrade:** Dedicated high-current N-channel MOSFET driver (IRLB3813PBF or higher current rating) with flyback protection diode on **GPIO11**.
- **Connector:** Dedicated 2-position Phoenix 5.08mm terminal block for high-duty heat exchanger recirculating pump.

### 3. Closed-Loop Fluid Flow Sensor Header
- **New Connector:** 3-pin 2.54mm header / Phoenix terminal.
- **Signals:**
  - Pin 1: `+3.3V` / `+5V` Power
  - Pin 2: `GND`
  - Pin 3: `FLOW_SENSE` Signal (GPIO input with 10kΩ pull-up resistor and noise filter capacitor).

---

## 📂 Related Files & Documentation

- Current Board Schematic & Specs: [`Project Files/PCB Design/Control Board.md`](Control%20Board.md)
- Induction Firmware Location: [`Project Files/Induction Heating Prototype/Firmware`](../Induction%20Heating%20Prototype/Firmware)

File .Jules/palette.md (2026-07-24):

## 2024-05-18 - Added keyboard accessibility to presentation deck
**Learning:** The presentation deck had a `#present-btn` that only indicated its action via a FontAwesome icon (`<i class="fa-solid fa-desktop"></i>`). While there was text "Present", screen readers could get confused by the icon without `aria-hidden="true"`. Furthermore, when switching to presentation mode, there was no shortcut hint. Adding `aria-label` and `title` to the button and dynamically updating them via JavaScript improves both screen reader experience and regular mouse/keyboard accessibility by exposing the `(Esc)` hint. Also added `:focus-visible` to interactive elements to help keyboard navigators, matching the color theme (`#B89E6B`).
**Action:** Always add `aria-hidden="true"` to pure decorative FontAwesome icons, add `aria-label`/`title` tooltips for action buttons, and remember to update `aria-label` state via JavaScript for toggle buttons. Ensure `:focus-visible` outlines match the design system's accent color.
## 2026-06-16 - Presentation Mode Keyboard UX
**Learning:** In custom presentation modes triggered by a button click, leaving focus on the button causes spacebar navigation to double-trigger the click event, exiting the mode. Also, default keyboard events (like Space or Arrows) can cause unwanted scrolling if not prevented.
**Action:** Use `.blur()` on toggle buttons after activation if the mode radically alters the UI, and add `e.preventDefault()` in keyboard navigation listeners for custom UI states.

## 2024-03-24 - Custom Presentation UX Feedback
**Learning:** When building custom HTML presentation decks (like `Biochar_Toilet_Slide_Deck.html`), native browser progress and navigation cues are lost. Adding a fixed visual progress bar with ARIA progressbar roles, and updating fullscreen toggle buttons' `title` and `aria-label` to explicitly list keyboard shortcuts (e.g. Space/Arrows), significantly improves the discoverability of navigation and overall screen reader accessibility.
**Action:** Always include an ARIA-enabled progress indicator for multi-step or paginated custom UI views, and explicitly state hidden keyboard navigation shortcuts in the ARIA labels of the UI controls that initiate those views.

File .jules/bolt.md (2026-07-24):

## 2025-02-14 - HTML Presentation Deck Media Loading
**Learning:** Native `loading="lazy"` for images and `preload="none"` for `<video>` tags are highly effective, low-risk frontend performance patterns for large slide decks like `Presentations/Biochar_Toilet_Slide_Deck.html` that default to loading all assets synchronously. Avoiding lazy loading on above-the-fold content prevents LCP penalties while still saving bandwidth on below-the-fold media.
**Action:** Always verify if large media assets in HTML/React/Vue components are loaded synchronously and default to using native lazy loading/preloading attributes for anything off-screen. Use Playwright to visually assert that these HTML-level optimizations do not break the CSS styling or DOM structure.
## 2025-02-14 - Throttling Resize Events in Presentation Deck
**Learning:** In the `Biochar_Toilet_Slide_Deck.html` presentation, window resize event listeners that trigger DOM layout recalculations (like `scaleActiveSlide`) must be throttled to prevent layout thrashing and main-thread blocking. A simple `window.addEventListener('resize', scaleActiveSlide)` causes performance issues during window adjustments.
**Action:** When adding resize event listeners in vanilla JS frontend code, always use a `requestAnimationFrame` (or similar) throttle to ensure DOM updates are capped at the display refresh rate (e.g., ~60fps).
## 2025-02-14 - Caching repeated remote asset fetches during export
**Learning:** The offline export script (`Presentations/export_offline.py`) was repeatedly fetching the same remote CSS and font assets via `requests.get()` because the same URLs were referenced multiple times in the HTML and CSS. This caused the script to be significantly slower and waste network requests.
**Action:** When writing or optimizing scripts that fetch remote assets or read local files, always introduce a memory cache (e.g., a dictionary) to avoid redundant I/O operations for identical paths/URLs.

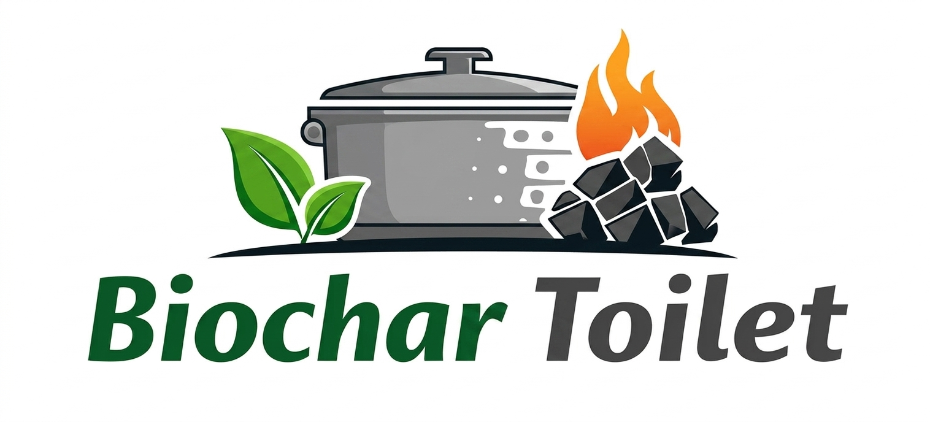
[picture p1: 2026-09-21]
Presentations/s-blob-v1-IMAGE-u5mOaW5JDZ4.png

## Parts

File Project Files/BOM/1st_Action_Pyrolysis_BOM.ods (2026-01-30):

 | Pyro-T Project BOM: 1st Actionable Item: Achieve Pyrolysis
# | Nomenclature | Description | Order Link | Units | Cost | Total (pretax)
1 | Pressure Vessel: 12L (12.2qt) | Hawkins 12 Liter Classic Pressure Cooker, Best Inner Lid Cooker, Silver (CL412) | Amazon: Hawkins 12L Order Page (https://www.amazon.com/dp/B00VNMLIZU/?th=1) | 1ea | $78.98 | $860.16
2 | 1” Solenoid: Normally Open | U.S. Solid 1 inch Solenoid Valve - Stainless Steel 110V AC Solenoid Valve, Normally Open, Viton Seal | Amazon: 1" Solenoid: Normally Open1 (https://www.amazon.com/inch-Solenoid-Valve-Stainless-Normally/dp/B0CMXJ1S2Y/?th=1) | 1ea | $58.99
3 | 1800W Induction Heater-Module Kit | 1800W 12V-48V ZVS Low Voltage DC Induction Heater Module PCB Board,Heat Induction Tool for Quenching, Annealing and Other Heat Treatments,DIY High Frequency Flyback Driver Heater | Amazon: Induction Heater Kit (https://www.amazon.com/Induction-Quenching-Annealing-Treatments-Frequency/dp/B0DM8FRKRS/?th=1) | 1ea | $64.99
4 | 2400W AC-DC Power Supply | MEAN WELL RSP-2400-48 AC to DC Power Supply, Single Output, 48 Volt, 50 Amp, 2.4kw | Amazon: Power Supply: 2400W (https://www.amazon.com/Power-Supply-Single-Output-2-4kw/dp/B005T8YGR6/) | 1ea | $358.93
5 | Carbon Monoxide Detector | Kidde Carbon Monoxide Detector, Battery Powered CO Alarm with LEDs, Test-Reset Button, Low Battery Indicator, Portable | Amazon: Carbon Monoxide Detector (https://www.amazon.com/Kidde-Monoxide-Detector-Test-Reset-Indicator/dp/B0DT1MGCKK) | 1ea | $23.97
6 | Dual-Channel Thermocouple & Meter | Dual-Channel K/J Thermocouple Thermometer with 4 K-Type Thermocouples -328°F ~ 2501°F Measurement Range HVAC Temperature Meter Gauge with Data Hold, MAX/MIN/AVG, Hi/Lo Backlit Alarm, ADJ Compensation | Amazon: Dual-Thermocouple-Meter (https://www.amazon.com/Landtek-Thermocouple-Thermometer-328-2501°F-Compensation/dp/B0C4YL76WY?s=industrial) | 1ea | $28.99
7 | Ceramic Sheath: Thermocouple | High Temperature Ceramic Protection Tube Sheath for K-Type Thermocouple for Kiln Furnace for Pottery, Glass Fusing, Metal Working 8 inch Long | Amazon: Ceramic Sheath (https://www.amazon.com/Temperature-Ceramic-Protection-Thermocouple-Furnace/dp/B0CQTSTKYP) | 1ea | $25.99
8 | 1” Bulkhead fitting | 1" Female Bulkhead Water Tank Connector Stainless Steel Thru-bulk Fitting | 1" Female Bulkhead Water Tank Connector Stainless Steel Thru-bulk Fitting (https://www.amazon.com/Bulkhead-Connector-Stainless-Thru-Bulk-Fitting/dp/B07X41NXN3/?th=1) | 1ea | $12.99
9 | High Heat Silicone Rubber | Mold Max 60 - High Heat Resistant Silicone Rubber Compound - Gallon Unit | Mold Max 60 - High Heat Resistant Silicone Rubber Compound - Gallon Uni (https://www.amazon.com/Mold-Max-60-Resistant-Silicone/dp/B09MJPZH22?th=1) | 1ea | $35.27
10 | Copper Tubing 1/4" OD x 0.187" ID x 50 Ft | Copper Tubing 1/4" OD x 0.187" ID x 50 Ft | Copper Tubing 1/4" OD x 0.187" ID x 50 Ft (https://www.amazon.com/GOORY-Copper-Tubing-0-185-Refrigeration/dp/B0DKSW5VL9/?th=1) | 1ea | $63.99
11 | Heat Exchanger | Heat Exchanger | Heat Exchanger (https://www.amazon.com/Milageto-Condenser-Refrigerator-Exchanger-Industrial/dp/B0FHH1HCQW?th=1) | 1ea | $43.09
12 | Hot Water Recirculating Pump | Hot Water Recirculating Pump, 93W, 110V Water Circulator Pump, Circulation Pump, 3/4″ G Thread to 1/2″ NPT Brass Adapter, Stainless Steel Head | Hot Water Recirculating Pump (https://www.amazon.com/VEVOR-Recirculating-Pump-93W-Circulating/dp/B09N92QGJD/?th=1) | 1ea | $43.99
13 | 1" Male Hex Nipple | 1" Male Hex Nipple Pipe Fittings, 304 Stainless Steel 1 inch NPT Threaded Pipe Adapter Fittings Equal Nipples Connectors | 1" nipple (https://www.amazon.com/Fittings-Stainless-Connectors-Connector-2pcs/dp/B0DFPN4Z1V/) | 1ea
14 | 2" Universal Catalytic Converter | 2" Universal Catalytic Converter | 2" Universal Catalytic Converter (https://www.amazon.com/ASOPARTS-Universal-Catalytic-Converter-Outlet/dp/B0CMLWHZ7C/) | 1ea
15 | High temp air filter |  |  | 1ea
16 | Coil stand-off |  |  | 1ea
17 | Crucible/fiberglass sack/bag | Holds, bentonite |  | 1ea
18 | Electrical Insulation ¼” bulkhead | Induction coil ¼” passthrough bulkhead |  | 1ea
18 | Bentonite Clay Granules | Unscented Clumping Clay Cat Litter | Unscented Clumping Clay Cat Litter (https://www.amazon.com/Dr-Elseys-Precious-Ultra-Litter/dp/B0009X0QSY/?th=1) | 1ea
19 | Black Iron Oxide - Fe3O4 | Black Iron Oxide - Fe3O4 - Natural - 5 Pounds | Black Iron Oxide - Fe3O4 (https://www.amazon.com/Black-Iron-Oxide-Natural-Pounds/dp/B004KICAVU) | 1ea | $19.99

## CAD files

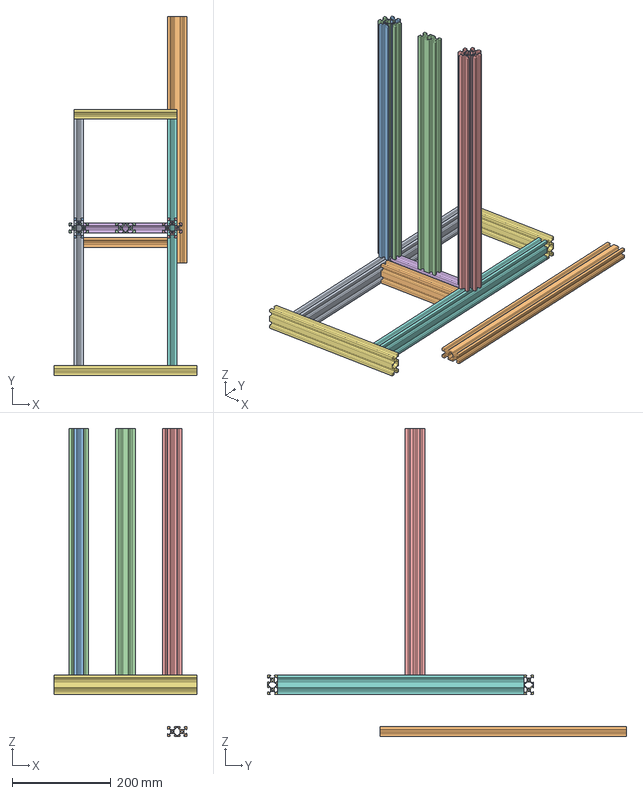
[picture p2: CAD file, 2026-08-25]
Project Files/CAD Files/Frame for Assembly_v2.2.FCStd
289.5 x 728.4 x 624.8 mm
20mmx40mm extruded aluminum
20mmx40mm extruded aluminum007
20mmx40mm extruded aluminum003
20mmx40mm extruded aluminum006
20mmx40mm extruded aluminum005
20mmx40mm extruded aluminum008
20mmx40mm extruded aluminum016
20mmx40mm extruded aluminum010
20mmx40mm extruded aluminum015
20mmx40mm extruded aluminum011
20mmx40mm extruded aluminum014
20mmx40mm extruded aluminum012
20mmx40mm extruded aluminum013
20mmx40mm extruded aluminum018
20mmx40mm extruded aluminum019
20mmx40mm extruded aluminum020

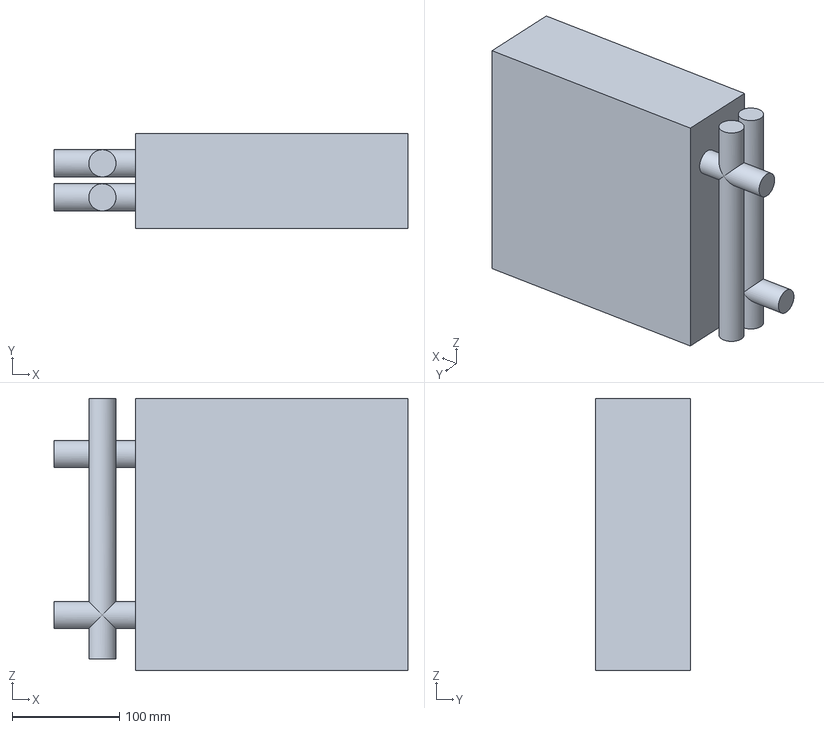
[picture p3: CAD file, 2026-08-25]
Project Files/CAD Files/Heat-Exchanger_HTL-10x10.FCStd
330.2 x 88.9 x 254.0 mm

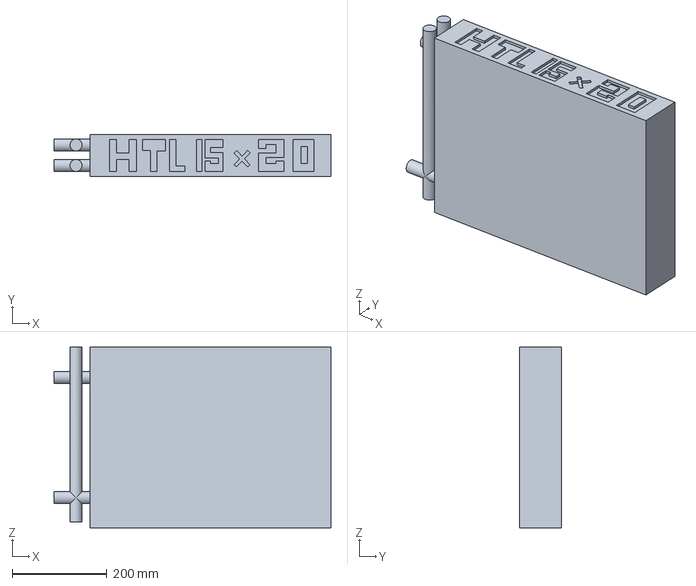
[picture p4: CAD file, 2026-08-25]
Project Files/CAD Files/Heat-Exchanger_HTL-15x20.FCStd
584.2 x 88.9 x 381.0 mm

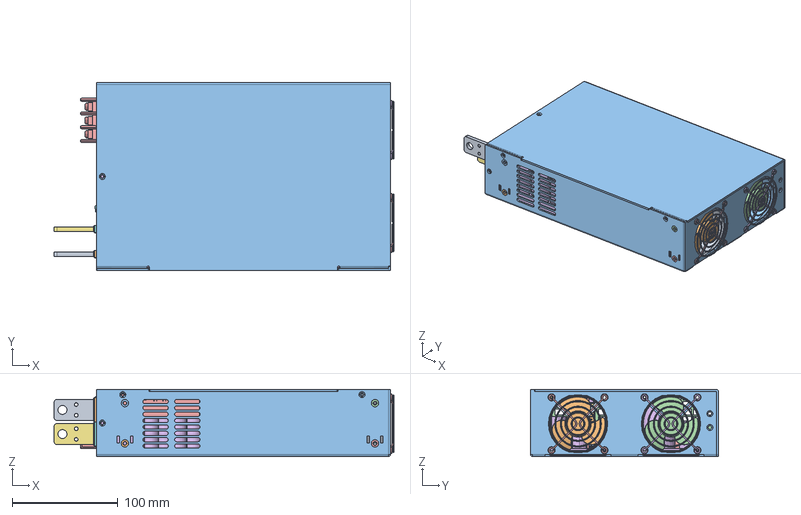
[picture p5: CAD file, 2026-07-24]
Project Files/CAD Files/RSP-2400-Mean_Well_PSU.FCStd
321.2 x 177.8 x 63.5 mm
FAN_4715KL40WB30_2
FAN
FAN_4715KL40WB30_001
FAN001
fan_a.1.1
fan_a.1.001
ff.1.1.1.1.1.1.2
ff.1.1.1.1.1.1.001
ff.1.1.1.1.1.1.002
ff.1.1.1.1.1.1.003
\S\JW\S\#\
M3-7L.1.2
M3-7L.1.001
ff.1.1.1.1.1.1.004
ff.1.1.1.1.1.1.005
ff.1.1.1.1.1.1.006
ff.1.1.1.1.1.1.007
ff.1.1.1.1.1.1.008
ff.1.1.1.1.1.1.009
ff.1.1.1.1.1.1.010
ff.1.1.1.1.1.1.011
M3-7L.1.002
M3-7L.1.003
M3-7L.1.004
M3-7L.1.005
M3-7L.1.006
\X2\02CB\X0\\S\0\S\[y
\S\/\S\%\S\#\.1
JJ.1
VR.1.1
VR.1.001
led.1.1.1
p1
p001
p2
p002
p003
p004
p005
p006
p007
p008
p009
p010
p011
p012
p013
VR.1.002
pcb2
pcb.1
CU1.1.2
GG.2.1.1
CU1.1.001
GG.2.1.001

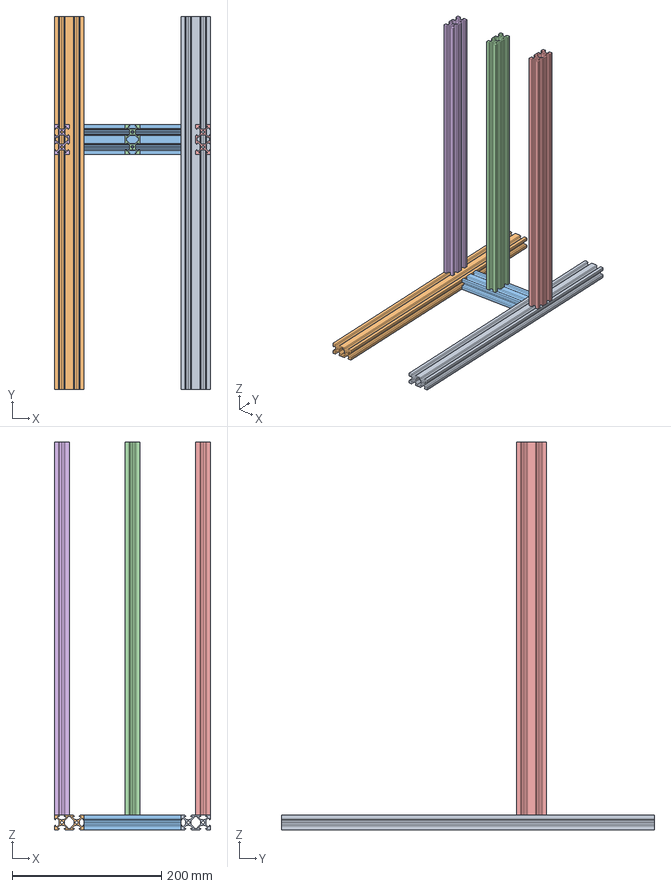
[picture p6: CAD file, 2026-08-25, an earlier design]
Project Files/CAD Files/Frame for Assembly_v2.0.FCStd
209.6 x 500.0 x 520.0 mm
20mmx40mm extruded aluminum
20mmx40mm extruded aluminum007
20mmx40mm extruded aluminum003
20mmx40mm extruded aluminum004
20mmx40mm extruded aluminum005
20mmx40mm extruded aluminum006

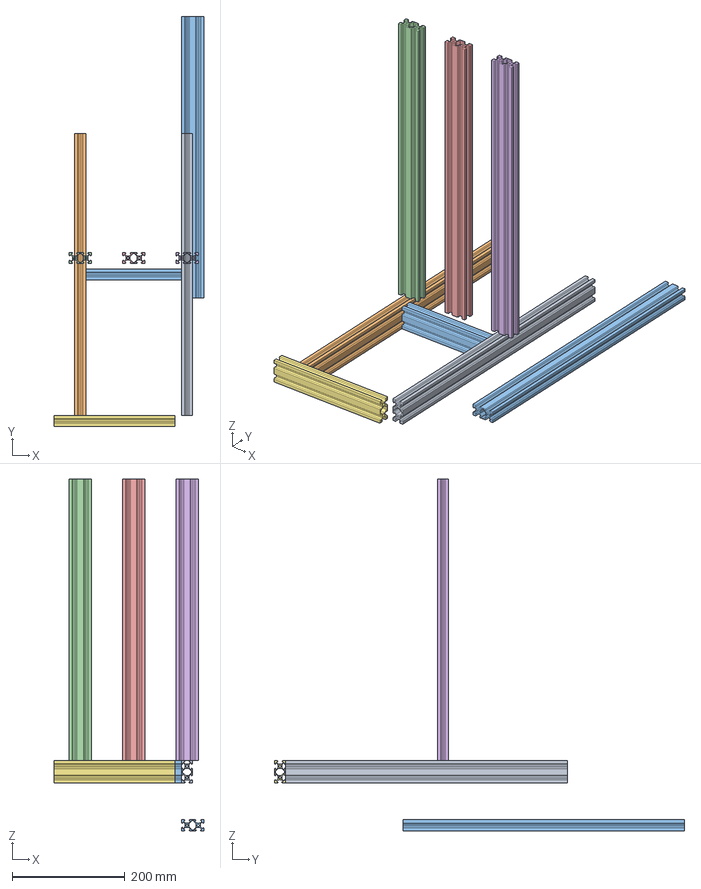
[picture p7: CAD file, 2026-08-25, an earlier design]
Project Files/CAD Files/Frame for Assembly_v2.1.FCStd
266.0 x 728.4 x 624.8 mm
20mmx40mm extruded aluminum
20mmx40mm extruded aluminum007
20mmx40mm extruded aluminum003
20mmx40mm extruded aluminum006
20mmx40mm extruded aluminum004
20mmx40mm extruded aluminum005
20mmx40mm extruded aluminum008

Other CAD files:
pressure_vessel.scad

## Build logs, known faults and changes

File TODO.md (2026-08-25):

# Project Tasks

Based on `README.md` and `DESIGN_IDEAS.md`.

- [x] Implement Valve Controller logic (to address the "small bug controlling the valve").
- [x] Create dedicated ESP32-H2 firmware for Dual Induction Heating Prototype (`Project Files/Induction Heating Prototype/Firmware`).
- [x] Enhance `dryness_monitor.py` with EMA noise filtering & temperature slope thresholding for low-moisture samples.
- [ ] Implement Heater Controller (mentioned as a future step).
- [ ] Design reaction vessel (ongoing).
- [ ] Implement emergency pop-off valve safety logic.

### Hardware Roadmap
- [ ] Implement PCB v0.4.0 Revision Plan (Dual MAX31855 SPI thermocouples, high-current pump driver, fluid flow sensor header — see [`PCB_v0.4.0_Induction_Revision_Plan.md`](Project%20Files/PCB%20Design/PCB_v0.4.0_Induction_Revision_Plan.md)).

### Testing and Benchmarking Improvements
- [x] Fix lazy test `test_cooling_or_steady_temp` in `test_dryness_monitor.py` which only tests slow temperature rise instead of actual cooling (temperature dropping).
- [x] Fix lazy test `test_threshold_crossing` in `test_valve_controller.py` which only tests the boundary value exactly, instead of a true threshold crossing (transition from below to above threshold).
- [x] Add tests simulating noisy and high-frequency sensor data for `dryness_monitor.py` (rate calculation is highly sensitive to window size).
- [x] Develop tests and benchmarks for low-moisture samples (like the bread charring experiment) where the dryness algorithm failed to trigger due to lack of distinct pressure change.

Safety considerations:

We need to identify a safe opening temperature that we can open the lid

We should examine the component mix of materials safety, in addition at different temperatures and pressure, since our dynamic system covers a lot of different regions. 

We should consider opening the valve before the lid, allowing air into the system. 

We should wear PPE, respirator, eye protection, and heat resistant gloves. 

### Presentation Improvements
- [ ] Develop a snappy script for the presentation to keep the narrative engaging.
- [ ] Add story narrative slides to the presentation covering:
  - How the team conceived of the project.
  - The heat transfer difficulty discovered during Hardhik's experiment.
  - Lawrence's invention of the induction approach.
  - Progress and difficulties with charring things.

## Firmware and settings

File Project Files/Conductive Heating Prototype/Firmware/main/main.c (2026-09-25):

/**
 * @file main.c
 * @brief Bio-Char Control Board v0.1.0 — Integrated Control System
 *        ESP-IDF port of the Arduino Dryness_test_PCB firmware
 *
 * Target:  ESP32-H2-DEVKITM-1-N4
 * SDK:     ESP-IDF v5.x
 *
 * Pin Configuration (corrected from PCB schematic — see notes below):
 *   GPIO0  → MAX31855 CLK
 *   GPIO1  → MAX31855 CS
 *   GPIO2  → MAX31855 DO (MISO — read-only, no MOSI needed)
 *   GPIO3  → Pressure Sensor ADC  (ADC1_CH2, 0–100 PSI via voltage divider)
 *   GPIO4  → SSR 1 / Heater       (active HIGH — drives BJT base to complete SSR circuit)
 *   GPIO5  → SSR 2                (reserved, not currently active — see commented code)
 *   GPIO8  → WS2812 RGB LED       (Status Indicator)
 *   GPIO10 → Solenoid Valve 1     (MOSFET-driven)
 *   GPIO11 → Solenoid Valve 2     (reserved, not currently active — see commented code)
 *   GPIO12 → Flush Button         (Active LOW with internal pull-up)
 *
 * PIN CONFIGURATION NOTES:
 *   GPIO14 and GPIO15 are reserved for 32 kHz RTC crystal on some variants.
 *   GPIO3 is shared with MTDI/JTAG.
 *
 * HEATER/SSR CHANGE vs ARDUINO VERSION:
 *   The Arduino version used active LOW (GPIO4 LOW = SSR ON, sinking to GND).
 *   This board uses a BJT (NPN) between the ESP32 GPIO and the SSR input:
 *     GPIO4 HIGH → BJT base HIGH → collector pulls SSR input LOW → SSR ON
 *     GPIO4 LOW  → BJT OFF → SSR input floating/HIGH → SSR OFF
 *   set_heater() has been updated accordingly.
 *
 * KNOWN ERRORS / ISSUES:
 *   1. ADC non-linearity at low raw values (<350): readings below ~0.5 PSI may
 *      fluctuate. The DRY_PRESSURE_MAX threshold (1.0 PSI) provides enough
 *      headroom for reliable detection.
 *   2. MAX31855 returns NAN on first read after power-on (~100ms settling time).
 *      The EMA initialisation handles this gracefully — temp_ema stays NAN until
 *      a valid reading arrives.
 *   3. GPIO3 on ESP32-H2 is shared with the JTAG interface (MTDI). Disconnect
 *      the JTAG debugger before running in production, or remap to GPIO4/5 if
 *      debugging under load is required.
 */

#include <stdio.h>
#include <math.h>
#include <string.h>
#include "freertos/FreeRTOS.h"
#include "freertos/task.h"
#include "driver/gpio.h"
#include "driver/spi_master.h"
#include "esp_adc/adc_oneshot.h"
#include "esp_log.h"
#include "esp_timer.h"
#include "esp_cpu.h"
#include "soc/gpio_reg.h"

static const char *TAG = "biochar";

// ===============================================================
// -------------------- MAX31855 THERMOCOUPLE --------------------
// ===============================================================
#define PIN_MAXCLK   GPIO_NUM_0    // MAX31855 Clock (SPI CLK)
#define PIN_MAXCS    GPIO_NUM_1    // MAX31855 Chip Select
#define PIN_MAXDO    GPIO_NUM_2    // MAX31855 Data Out (MISO — read-only)

// ===============================================================
// -------------------------- PINS --------------------------------
// ===============================================================
#define PIN_ADC_PRESSURE  ADC_CHANNEL_2   // GPIO3 — Pressure sensor (ADC1_CH2)
#define PIN_VALVE         GPIO_NUM_10     // GPIO10 — Solenoid Valve 1 (MOSFET)
#define PIN_HEATER        GPIO_NUM_4      // GPIO4 — SSR 1 (active HIGH → BJT → SSR)
#define PIN_LED_WS2812    GPIO_NUM_8      // GPIO8  — Onboard WS2812 RGB Status LED
#define PIN_FLUSH_BUTTON  GPIO_NUM_12     // GPIO12 — Manual Flush Button (Active LOW with internal pull-up)

// Reserved for future use — uncomment when second SSR and valve are needed
// #define PIN_SSR2    GPIO_NUM_5    // GPIO5  — SSR 2 circuit (not currently active)
// #define PIN_VALVE2  GPIO_NUM_11   // GPIO11 — Solenoid Valve 2 (not currently active)

// ===============================================================
// ------------------- PRESSURE CALIBRATION ----------------------
// ===============================================================
#define ADC_ZERO      320.0f    // ADC raw value at 0 PSI
#define ADC_FULL      3008.0f   // ADC raw value at 100 PSI

// ===============================================================
// --------------------- LOGARITHMIC VALVE CONTROL ---------------
// ===============================================================
#define MIN_SEAL_PRESSURE  4.0f    // Hard floor to preserve seal integrity
#define TARGET_PRESSURE    8.0f    // Maximum target pressure before safety limits
#define TARGET_TEMP_C      121.0f  // Target temperature for sterilization release
#define VALVE_WINDOW_MS    2000    // Valve maximum burst duration (ms)
#define VALVE_COOLDOWN_MS  2000    // Mandatory cooldown duration between bursts (ms)

// ===============================================================
// ------------------- DRY DETECTION (PRESSURE) ------------------
// ===============================================================
#define CYCLE_START_PSI      2.0f       // Pressure must exceed this to start a cycle
#define REPRESSURIZE_TIMEOUT_MS  (5UL * 60UL * 1000UL) // 5 minutes timeout to drop target pressure
#define MAX_CYCLE_TIME_MS    (30UL * 60UL * 1000UL) // 30 minutes maximum cycle duration
#define LONG_PRESS_RESET_MS  3000LL     // 3 seconds long-press to reset emergency trip

// ===============================================================
// ------------------ HEATER TEMPERATURE CONTROL -----------------
// ===============================================================
#define SETPOINT_C   200.0f    // Target temperature (°C)
#define HYST_C       2.0f      // Hysteresis band (°C)
#define KP           0.03f     // Proportional gain
#define EMA_ALPHA    0.10f     // Exponential moving average weight
#define WINDOW_MS    2000      // PWM window period (ms)

// ===============================================================
// --------------------------- STATE -----------------------------
// ===============================================================
typedef enum {
    STATE_OFF,
    STATE_HEATING,
    STATE_COOLING,
    STATE_ERROR
} system_state_t;

static system_state_t current_state = STATE_OFF;
static int negative_pressure_counter = 0;
static int64_t cooling_start_time = 0;
static float base_temp_for_runaway = -1.0f;
static float base_temp_for_absolute_runaway = -1.0f;

#define STAGNATION_WINDOW_SIZE 180
static float heating_temp_history[STAGNATION_WINDOW_SIZE];
static int64_t heating_time_history[STAGNATION_WINDOW_SIZE];
static int history_head = 0;
static int history_count = 0;
static int64_t last_history_record_time = 0;

static bool    valve_on            = false;
static bool    cycle_active        = false;
static bool    dry_latched         = false;
static bool    has_pressurized     = false;
static bool    emergency_tripped   = false;
static int64_t dry_candidate_start = 0;
static int64_t cycle_start_time    = 0;
static int64_t button_press_start  = 0;
static bool    button_was_pressed  = false;
static bool    long_press_handled  = false;
static float   temp_ema            = NAN;
static int64_t window_start        = 0;
static int64_t valve_window_start  = 0;

static spi_device_handle_t       max31855_handle;
static adc_oneshot_unit_handle_t adc_handle;

// ===============================================================
// -------------------------- HELPERS ----------------------------
// ===============================================================
static float fmap(float x, float in_min, float in_max, float out_min, float out_max) {
    return (x - in_min) * (out_max - out_min) / (in_max - in_min) + out_min;
}

static float adc_to_psi(int adc_raw) {
    return fmap((float)adc_raw, ADC_ZERO, ADC_FULL, 0.0f, 100.0f);
}

static void set_heater(bool on) {
    // Active HIGH: GPIO4 HIGH → BJT base HIGH → collector completes SSR circuit → SSR ON
    // Active LOW (off):  GPIO4 LOW  → BJT OFF → SSR OFF
    gpio_set_level(PIN_HEATER, (on && !emergency_tripped && current_state == STATE_HEATING) ? 1 : 0);
}

// ===============================================================
// -------------------- WS2812 RGB LED DRIVER --------------------
// ===============================================================
static void set_led_color(uint8_t r, uint8_t g, uint8_t b) {
    uint8_t grb[3] = {g, r, b};
    uint32_t mask = (1UL << PIN_LED_WS2812);

    portDISABLE_INTERRUPTS();
    for (int i = 0; i < 3; i++) {
        uint8_t byte = grb[i];
        for (int bit = 7; bit >= 0; bit--) {
            if (byte & (1 << bit)) {
                // Bit 1: HIGH ~800ns (77 cycles at 96MHz), LOW ~350ns (34 cycles)
                REG_WRITE(GPIO_OUT_W1TS_REG, mask);
                uint32_t start = esp_cpu_get_cycle_count();
                while ((esp_cpu_get_cycle_count() - start) < 77) { __asm__ __volatile__("nop"); }

                REG_WRITE(GPIO_OUT_W1TC_REG, mask);
                start = esp_cpu_get_cycle_count();
                while ((esp_cpu_get_cycle_count() - start) < 34) { __asm__ __volatile__("nop"); }
            } else {
                // Bit 0: HIGH ~350ns (34 cycles at 96MHz), LOW ~800ns (77 cycles)
                REG_WRITE(GPIO_OUT_W1TS_REG, mask);
                uint32_t start = esp_cpu_get_cycle_count();
                while ((esp_cpu_get_cycle_count() - start) < 34) { __asm__ __volatile__("nop"); }

                REG_WRITE(GPIO_OUT_W1TC_REG, mask);
                start = esp_cpu_get_cycle_count();
                while ((esp_cpu_get_cycle_count() - start) < 77) { __asm__ __volatile__("nop"); }
            }
        }
    }
    portENABLE_INTERRUPTS();

    // WS2812 Reset pulse > 50us (5000 cycles)
    REG_WRITE(GPIO_OUT_W1TC_REG, mask);
    uint32_t start = esp_cpu_get_cycle_count();
    while ((esp_cpu_get_cycle_count() - start) < 5000) { __asm__ __volatile__("nop"); }
}

// ===============================================================
// -------------------- MAX31855 SPI READ ------------------------
// ===============================================================
/**
 * Reads a 32-bit frame from the MAX31855 over SPI.
 *
 * Frame layout:
 *   Bits [31:18] — Thermocouple temp, 14-bit signed, 0.25°C/LSB
 *   Bit  [16]   — Fault bit (1 = fault present)
 *   Bits [15:4] — Internal junction temp (not used here)
 *   Bits [3:0]  — Fault flags (OC, SCG, SCV)
 */
static esp_err_t max31855_read(float *temp_c, bool *fault) {
    uint8_t rx_buf[4] = {0};

    spi_transaction_t t = {
        .length    = 32,
        .rx_buffer = rx_buf,
    };

    esp_err_t ret = spi_device_polling_transmit(max31855_handle, &t);
    if (ret != ESP_OK) return ret;

    uint32_t raw = ((uint32_t)rx_buf[0] << 24) |
                   ((uint32_t)rx_buf[1] << 16) |
                   ((uint32_t)rx_buf[2] <<  8) |
                   ((uint32_t)rx_buf[3]);

    *fault = (raw & (1UL << 16)) != 0;

    // Sign-extend the 14-bit thermocouple value
    int16_t tc_raw = (int16_t)((raw >> 18) & 0x3FFF);
    if (tc_raw & 0x2000) tc_raw |= 0xC000;
    *temp_c = tc_raw * 0.25f;

    return ESP_OK;
}

// ===============================================================
// ----------------------- INITIALISATION ------------------------
// ===============================================================
static void init_spi(void) {
    spi_bus_config_t bus_cfg = {
        .miso_io_num   = PIN_MAXDO,
        .mosi_io_num   = -1,           // MAX31855 is read-only, no MOSI
        .sclk_io_num   = PIN_MAXCLK,
        .quadwp_io_num = -1,
        .quadhd_io_num = -1,
        .max_transfer_sz = 4,
    };
    ESP_ERROR_CHECK(spi_bus_initialize(SPI2_HOST, &bus_cfg, SPI_DMA_CH_AUTO));

    spi_device_interface_config_t dev_cfg = {
        .clock_speed_hz = 1 * 1000 * 1000,  // 1 MHz (MAX31855 max: 5 MHz)
        .mode           = 0,                  // CPOL=0, CPHA=0
        .spics_io_num   = PIN_MAXCS,
        .queue_size     = 1,
    };
    ESP_ERROR_CHECK(spi_bus_add_device(SPI2_HOST, &dev_cfg, &max31855_handle));
}

static void init_adc(void) {
    adc_oneshot_unit_init_cfg_t unit_cfg = {
        .unit_id = ADC_UNIT_1,
    };
    ESP_ERROR_CHECK(adc_oneshot_new_unit(&unit_cfg, &adc_handle));

    adc_oneshot_chan_cfg_t chan_cfg = {
        .bitwidth = ADC_BITWIDTH_12,
        .atten    = ADC_ATTEN_DB_12,   // Full 0–3.3 V range
    };
    ESP_ERROR_CHECK(adc_oneshot_config_channel(adc_handle, PIN_ADC_PRESSURE, &chan_cfg));
}

static void init_gpio(void) {
    gpio_config_t io_conf = {
        .pin_bit_mask  = (1ULL << PIN_VALVE) | (1ULL << PIN_HEATER) | (1ULL << PIN_LED_WS2812),
        .mode          = GPIO_MODE_OUTPUT,
        .pull_up_en    = GPIO_PULLUP_DISABLE,
        .pull_down_en  = GPIO_PULLDOWN_ENABLE,   // Pull-down keeps BJT off at boot
        .intr_type     = GPIO_INTR_DISABLE,
    };
    ESP_ERROR_CHECK(gpio_config(&io_conf));

    gpio_set_level(PIN_VALVE,      0);   // Valve 1 OFF
    gpio_set_level(PIN_HEATER,     0);   // SSR 1 OFF (BJT base LOW)
    gpio_set_level(PIN_LED_WS2812, 0);   // WS2812 LED pin LOW

    set_led_color(0, 0, 0);               // WS2812 reset

    // Configure Flush Button input
    gpio_config_t btn_conf = {
        .pin_bit_mask  = (1ULL << PIN_FLUSH_BUTTON),
        .mode          = GPIO_MODE_INPUT,
        .pull_up_en    = GPIO_PULLUP_ENABLE,     // Pull-up resistor (Active LOW button press to GND)
        .pull_down_en  = GPIO_PULLDOWN_DISABLE,
        .intr_type     = GPIO_INTR_DISABLE,
    };
    ESP_ERROR_CHECK(gpio_config(&btn_conf));

    // Uncomment when SSR 2 and Valve 2 circuits are populated on the board:
    // gpio_config_t io_conf2 = {
    //     .pin_bit_mask  = (1ULL << PIN_SSR2) | (1ULL << PIN_VALVE2),
    //     .mode          = GPIO_MODE_OUTPUT,
    //     .pull_up_en    = GPIO_PULLUP_DISABLE,
    //     .pull_down_en  = GPIO_PULLDOWN_ENABLE,
    //     .intr_type     = GPIO_INTR_DISABLE,
    // };
    // ESP_ERROR_CHECK(gpio_config(&io_conf2));
    // gpio_set_level(PIN_SSR2,   0);
    // gpio_set_level(PIN_VALVE2, 0);
}

// ===============================================================
// ------------------------- MAIN TASK ---------------------------
// ===============================================================
static void transition_to(system_state_t new_state, float current_temp, int64_t now) {
    if (current_state == STATE_ERROR) return;

    current_state = new_state;

    if (new_state == STATE_COOLING || new_state == STATE_OFF) {
        cooling_start_time = now;
    }

    if (new_state == STATE_OFF || new_state == STATE_COOLING) {
        base_temp_for_absolute_runaway = current_temp;
        base_temp_for_runaway = current_temp;
    }

    if (new_state == STATE_HEATING) {
        history_head = 0;
        history_count = 0;
        last_history_record_time = 0;
        if (!isnan(current_temp)) {
            heating_temp_history[0] = current_temp;
            heating_time_history[0] = now;
            history_head = 1;
            history_count = 1;
            last_history_record_time = now;
        }
    }

    if (new_state == STATE_ERROR) {
        emergency_tripped = true;
        ESP_LOGE(TAG, "🚨 SYSTEM ENTERED ERROR STATE: All heaters DISABLED, valve FORCED OPEN!");
    }
}
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
void app_main(void) {
    init_spi();
    init_adc();
    init_gpio();

    xTaskCreate(control_task, "control_task", 4096, NULL, 5, NULL);
}

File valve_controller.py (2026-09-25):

import math
import time

class ValveController:
    """
    Controls the steam valve for the Biochar Toilet reaction vessel with safety interlocks.
    Uses calculated single-shot duration with cooldown for logarithmic pressure release.
    Also implements dynamic target pressure dropping and dryness detection based on repressurization timeouts.
    """
    def __init__(self, target_pressure=8.0, target_temperature=121.0, min_seal_pressure=4.0, max_safe_pressure=18.0, max_safe_temperature=250.0, window_ms=2000, cooldown_ms=2000, repressurize_timeout_ms=300000):
        self.initial_target_pressure = target_pressure
        self.target_temperature = target_temperature
        self.min_seal_pressure = min_seal_pressure
        self.max_safe_pressure = max_safe_pressure
        self.max_safe_temperature = max_safe_temperature

        self.valve_open = False
        self.release_active = False
        self.emergency_tripped = False

        self.dynamic_target_pressure = target_pressure
        self.dry_latched = False

        self.window_ms = window_ms
        self.cooldown_ms = cooldown_ms
        self.burst_start_time = 0
        self.burst_duration = 0
        self.cooldown_start_time = -self.cooldown_ms

        self.repressurize_timeout_ms = repressurize_timeout_ms
        self.repressurize_timer_start = 0
        self.is_repressurizing = False

        # Calculate bounds
        self._update_bounds()

    def _update_bounds(self):
        self.vent_lower_bound = max(self.min_seal_pressure, self.dynamic_target_pressure - 2.0)

    def get_time_ms(self):
        return time.time() * 1000

    def update(self, pressure, temperature, current_time_ms=None):
        if current_time_ms is None:
            current_time_ms = self.get_time_ms()

        # Emergency Interlock Check
        if pressure >= self.max_safe_pressure or temperature >= self.max_safe_temperature:
            self.emergency_tripped = True
            self.valve_open = True
            return

        if self.emergency_tripped:
            self.valve_open = True
            self.release_active = False
            return

        # ------------------- DRYNESS & DYNAMIC TARGET LOGIC -------------------
        if not self.valve_open and not self.release_active and not self.dry_latched:
            # We are waiting for pressure to build.
            if temperature >= 100.0 and pressure < self.dynamic_target_pressure:
                if not self.is_repressurizing:
                    self.is_repressurizing = True
                    self.repressurize_timer_start = current_time_ms
                else:
                    # Check for timeout
                    if (current_time_ms - self.repressurize_timer_start) >= self.repressurize_timeout_ms:
                        if self.dynamic_target_pressure > self.min_seal_pressure:
                            self.dynamic_target_pressure = max(self.min_seal_pressure, self.dynamic_target_pressure - 1.0)
                            self._update_bounds()
                            print(f"[Valve] Timeout reached. Dropped target pressure to {self.dynamic_target_pressure} PSI")
                            self.repressurize_timer_start = current_time_ms # Reset timer for new target
                        else:
                            # Reached minimum seal pressure and STILL timed out. We are dry.
                            self.dry_latched = True
                            self.is_repressurizing = False
                            print(f"[Valve] DRY LATCHED: Failed to reach minimum seal pressure ({self.min_seal_pressure} PSI)")
            else:
                self.is_repressurizing = False
        else:
            # If valve is open or releasing, we are not repressurizing in the 'stuck' sense
            self.is_repressurizing = False

        # ------------------- VALVE LOGIC -------------------
        if not self.release_active and pressure >= self.dynamic_target_pressure and temperature >= self.target_temperature:
            self.release_active = True
            print(f"[Valve] Target {self.dynamic_target_pressure} PSI reached. Initiating release.")

        if self.release_active:
            # CRITICAL SAFETY FLOOR
            if pressure <= self.vent_lower_bound:
                self.valve_open = False
                self.release_active = False
                print(f"[Valve] Dropped below vent bound {self.vent_lower_bound} PSI. Closing.")
            else:
                if self.valve_open:
                    # We are in an active burst
                    if (current_time_ms - self.burst_start_time) >= self.burst_duration:
                        # Burst finished, close valve and start cooldown
                        self.valve_open = False
                        self.cooldown_start_time = current_time_ms
                else:
                    # Valve is closed. Are we in cooldown?
                    if (current_time_ms - self.cooldown_start_time) >= self.cooldown_ms:
                        # Cooldown finished (or hasn't happened yet), start a new burst
                        clamped_pressure = min(pressure, self.dynamic_target_pressure)
                        range_p = self.dynamic_target_pressure - self.vent_lower_bound

                        if range_p <= 0:
                            duty_cycle = 0.0
                        else:
                            t = (clamped_pressure - self.vent_lower_bound) / range_p
                            log_factor = math.log1p(t * 1.71828) / 1.0
                            duty_cycle = max(0.0, min(1.0, log_factor))

                        self.burst_duration = duty_cycle * self.window_ms
                        self.burst_start_time = current_time_ms
                        self.valve_open = True
        else:
            self.valve_open = False

    def is_open(self):
        return self.valve_open

    def is_emergency_tripped(self):
        return self.emergency_tripped

    def reset(self, current_time_ms=None):
        self.valve_open = False
        self.release_active = False
        self.emergency_tripped = False
        self.burst_start_time = 0
        self.cooldown_start_time = -self.cooldown_ms
        self.dynamic_target_pressure = self.initial_target_pressure
        self.dry_latched = False
        self.is_repressurizing = False
        self._update_bounds()

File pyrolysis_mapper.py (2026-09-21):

#!/usr/bin/env python3
import sys
import serial
import serial.tools.list_ports
import time
import math
import csv
import re
from datetime import datetime

# We expect serial lines like:
# P=12.34psi | Valve=CLOSED | Pump=OFF | MainHeater=ON | CatHeater=ON | TRIP=NO | DRY=NO | CycleActive=YES | Duty=100%
# T_ema=123.4°C

def find_serial_ports():
    ports = serial.tools.list_ports.comports()
    return [port.device for port in ports]

def select_serial_port():
    ports = find_serial_ports()
    if not ports:
        print("No serial ports found. Please connect the device and try again.")
        sys.exit(1)

    print("\nAvailable serial ports:")
    for i, port in enumerate(ports):
        print(f"[{i}] {port}")

    while True:
        try:
            choice = input("\nSelect a port by number: ")
            index = int(choice)
            if 0 <= index < len(ports):
                return ports[index]
            else:
                print("Invalid choice, please select a valid number.")
        except ValueError:
            print("Please enter a valid number.")

def estimate_cycle_time(mass_g):
    # Base configuration: 88g = 2 hours (120 minutes)
    # The user noted it should be exponential (larger mass = disproportionately longer dwell)
    # A simple exponential model: Time = k * mass^n
    # Let's say n = 1.5, we can solve for k.
    # 120 = k * (88)^1.5  -> k = 120 / (88)^1.5 = 120 / 825.8 = 0.1453
    # Time(mins) = 0.1453 * (mass_g)^1.5

    # Just to be safe, if mass is tiny, return something reasonable
    if mass_g <= 0:
        return 0

    k = 120.0 / math.pow(88.0, 1.5)
    estimated_minutes = k * math.pow(mass_g, 1.5)
    return estimated_minutes

def parse_line_for_pressure(line):
    # Extract "P=12.34psi"
    match = re.search(r'P=([\d\.]+)psi', line)
    if match:
        return float(match.group(1))
    return None

def parse_line_for_temp(line):
    # Extract "T_ema=123.4°C"
    match = re.search(r'T_ema=([\d\.]+)', line)
    if match:
        return float(match.group(1))
    return None

def main():
    print("=== Pyrolysis Cycle Estimator and Data Logger ===")

    # Ask for mass
    try:
        mass_input = input("Enter the input sample mass of water in grams (e.g. 88): ")
        mass_g = float(mass_input)
    except ValueError:
        print("Invalid mass entered. Exiting.")
        sys.exit(1)

    # Calculate estimated cycle time
    estimated_mins = estimate_cycle_time(mass_g)
    print(f"\nEstimated Dwell Time for {mass_g}g: {estimated_mins:.2f} minutes ({estimated_mins/60.0:.2f} hours)\n")

    # Select port
    port_name = select_serial_port()
    baud_rate = 115200 # Standard ESP-IDF baud

    print(f"\nConnecting to {port_name} at {baud_rate} baud...")

    # Prepare CSV logger
    timestamp_str = datetime.now().strftime("%Y%m%d_%H%M%S")
    csv_filename = f"pyrolysis_log_{timestamp_str}.csv"

    print(f"Logging data to: {csv_filename}")
    print("Press Ctrl+C to stop logging.\n")

    try:
        ser = serial.Serial(port_name, baud_rate, timeout=1.0)
    except Exception as e:
        print(f"Failed to open serial port {port_name}: {e}")
        sys.exit(1)

    # Open CSV file
    with open(csv_filename, mode='w', newline='') as csv_file:
        writer = csv.writer(csv_file)
        writer.writerow(["Timestamp", "Elapsed_Time_Mins", "Mass_g", "Estimated_Total_Time_Mins", "Pressure_PSI", "Temp_C", "Pyrolysis_State_Estimate_%"])

        start_time = time.time()
        last_pressure = None

        try:
            while True:
                line = ser.readline().decode('utf-8', errors='replace').strip()
                if not line:
                    continue

                print(f"[Serial] {line}")

                # Try to parse Pressure and Temperature. They might be on different lines.
                p = parse_line_for_pressure(line)
                if p is not None:
                    last_pressure = p

                t = parse_line_for_temp(line)

                if t is not None and last_pressure is not None:
                    # We have both a recent pressure and a new temp reading. Log them.
                    current_time = time.time()
                    elapsed_mins = (current_time - start_time) / 60.0

                    # Rough estimate of progress
                    progress_pct = (elapsed_mins / estimated_mins) * 100.0 if estimated_mins > 0 else 0
                    if progress_pct > 100.0:
                        progress_pct = 100.0

                    writer.writerow([
                        datetime.now().isoformat(),
                        f"{elapsed_mins:.2f}",
                        f"{mass_g:.2f}",
                        f"{estimated_mins:.2f}",
                        f"{last_pressure:.2f}",
                        f"{t:.2f}",
                        f"{progress_pct:.1f}"
                    ])
                    csv_file.flush() # Ensure it writes to disk

                    # Reset so we wait for the next full pair
                    last_pressure = None

        except KeyboardInterrupt:
            print("\nLogging stopped by user.")
        finally:
            ser.close()
            print(f"Data saved to {csv_filename}")

if __name__ == "__main__":
    main()

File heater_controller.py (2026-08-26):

import time

class HeaterController:
    """
    Controls a heating element (resistive or induction SSR driver) for bio-char production.

    Provides temperature regulation using Proportional (P) control with a hysteresis band,
    time-window PWM duty cycle calculation, dry protection interlocks, and over-temperature safety cutoffs.
    """

    def __init__(self, target_setpoint=200.0, hysteresis=2.0, kp=0.03, window_ms=2000, max_safe_temp=250.0):
        """
        Initializes the HeaterController.

        Args:
            target_setpoint (float): Target operational temperature in °C (default 200.0 °C).
            hysteresis (float): Hysteresis band above setpoint to force duty to 0% in °C (default 2.0 °C).
            kp (float): Proportional gain for duty cycle calculation (default 0.03).
            window_ms (int): PWM window period in milliseconds (default 2000 ms).
            max_safe_temp (float): Hard upper thermal limit for safety shutoff in °C (default 250.0 °C).
        """
        self.target_setpoint = target_setpoint
        self.hysteresis = hysteresis
        self.kp = kp
        self.window_ms = window_ms
        self.max_safe_temp = max_safe_temp

        self.heater_on = False
        self.duty_cycle = 0.0
        self.overtemp_tripped = False
        self.dry_latched = False
        self.window_start_ms = 0

    def compute_duty_cycle(self, current_temp):
        """
        Computes the proportional PWM duty cycle (0.0 to 1.0) given current temperature.

        Args:
            current_temp (float): Current temperature reading in °C.

        Returns:
            float: Calculated duty cycle between 0.0 (0%) and 1.0 (100%).
        """
        if current_temp >= (self.target_setpoint + self.hysteresis):
            return 0.0

        error = self.target_setpoint - current_temp
        duty = self.kp * error

        if duty < 0.0:
            duty = 0.0
        elif duty > 1.0:
            duty = 1.0

        return duty

    def update(self, current_temp, now_ms=None, dry_latched=False):
        """
        Updates the heater state based on current temperature, time window, and safety inputs.

        Args:
            current_temp (float): Current temperature in °C.
            now_ms (int, optional): Current timestamp in milliseconds. Defaults to current system time.
            dry_latched (bool): Interlock signal indicating dry boiler protection latched.

        Returns:
            bool: True if heater output should be active, False otherwise.
        """
        if now_ms is None:
            now_ms = int(time.time() * 1000)

        self.dry_latched = dry_latched

        # Safety Check: Hard Overtemperature Trip
        if current_temp >= self.max_safe_temp:
            self.overtemp_tripped = True

        if self.overtemp_tripped or self.dry_latched:
            self.duty_cycle = 0.0
            self.heater_on = False
            return False

        # Calculate Duty Cycle
        self.duty_cycle = self.compute_duty_cycle(current_temp)

        # Time Window PWM Calculation
        if self.window_start_ms == 0 or (now_ms - self.window_start_ms) >= self.window_ms:
            self.window_start_ms = now_ms

        elapsed = now_ms - self.window_start_ms
        active_duration = int(self.duty_cycle * self.window_ms)

        self.heater_on = elapsed < active_duration
        return self.heater_on

    def is_on(self):
        """Returns True if the heater output is active."""
        return self.heater_on

    def is_overtemp_tripped(self):
        """Returns True if an over-temperature safety trip has occurred."""
        return self.overtemp_tripped

    def reset(self):
        """Resets the controller and clears safety trip states."""
        self.heater_on = False
        self.duty_cycle = 0.0
        self.overtemp_tripped = False
        self.dry_latched = False
        self.window_start_ms = 0

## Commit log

2025-12-25 Implement dryness detection algorithm and update README
    Created `dryness_monitor.py` which implements a `DrynessMonitor` class to detect when a sample is dry based on temperature and pressure trends. Specifically, it identifies the condition where tempera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
    Added `test_dryness_monitor.py` to unit test the algorithm with various scenarios including wet heating (both rise) and dry heating (only temp rises).
    Updated `README.md` to mark the algorithm task as completed and reference the new file.
2025-12-26 Add potted internal coil design to DESIGN_IDEAS.md
    [pressure_vessel.scad]
2025-12-26 Add Smart Lid design and update OpenSCAD model
    [pressure_vessel.scad]
2025-12-26 Ensure OpenSCAD code in DESIGN_IDEAS.md matches pressure_vessel.scad
2026-01-07 Refactor plumbing to side mount and clear lid
    - Moved steam exit port from lid to vessel side wall.
    - Created `side_plumbing_assembly` with flange, fitting, solenoid, and catalyst.
    - Rotated catalyst assembly 180 degrees to point down.
    - Removed plumbing components from `smart_lid_assembly` to keep lid clear.
    [pressure_vessel.scad]
2026-01-08 Update pressure vessel model with hollow induction coils, side ports, and pressure relief valve.
    - Modified `internal_coil_liner` to use hollow square-profile rings to simulate tubing.
    - Added two side ports for induction coil connections passing through the liner and vessel wall.
    - Added a thermocouple monitoring port on the vessel side wall near the rim.
    - Added a pressure relief valve to the `smart_lid_assembly`.
    - Removed the obsolete electrical feedthrough from the lid.
    - Ensured proper clearances for all new penetrations.
    [pressure_vessel.scad]
2026-01-29 Rename Project Files/Hawkins-12L-Vessel v1.0 to Project Files/CAD Files/Hawkins-12L-Vessel v1.0
2026-01-30 updated bom
    [1st_Action_Pyrolysis_BOM.ods]
2026-01-30 updated critical components
    [1st_Action_Pyrolysis_BOM.ods]
2026-02-14 Implement ValveController and create TODO list
2026-04-25 Add induction experimental data and observations
    Added experimental data for various materials used in induction heating tests, including observations on efficiency and thermal behavior.
2026-06-13 Fix Phase 1 heat source text in presentation deck
    Replaced incorrect reference to "Silicon Nitride igniter" with "Hot plate" in Presentations/Biochar_Toilet_Slide_Deck.html for the Phase 1 slide.
2026-06-13 Fix text overflow in Slide 14.1 (Induction Hardware Deep Dive)
    Applied inline CSS to reduce font sizes, line heights, margins, and padding specifically for the dense content on Slide 14.1, ensuring all five bullet points remain visible within the fixed slide container bounds without getting cut off at the bottom.
2026-06-13 Fix slide 14.1 text overflow via compact inline styling
    Applied reduced margins, paddings, and font sizes using inline styles
    specifically to Slide 14.1 ("Induction Hardware: Current Development Status")
    in `Biochar_Toilet_Slide_Deck.html` so that all bullet points
    fit completely within the fixed viewport dimensions without getting cut off.
2026-06-13 Fix vertical cutoff on Slide 14.2
    Reduces the margin and padding values of the 'From Kitchenware to Prototype' slide to prevent the bottom from vertically overflowing the fixed container.
2026-06-14 perf: Optimize high-frequency data storage in DrynessMonitor
    Replaced dictionary allocations with tuples in the `add_reading` method
    of `dryness_monitor.py`. This significantly reduces object creation
    overhead and memory usage by over 60% when storing high-frequency sensor
    data in the rolling history buffer. Unpacking logic in `is_dry` was
    updated accordingly.
    Added a specific performance learning to the `.jules/bolt.md` journal.
    [dryness_monitor.py]
2026-06-14 🎨 Palette: Improve presentation deck a11y & keyboard nav
2026-06-17 feat(presentation): add progress bar and a11y keyboard hints
    - Added a fixed presentation progress bar to provide visual feedback during full-screen presentation mode.
    - Updated the presentation mode toggle button to explicitly announce keyboard shortcuts via its title and aria-label.
    - Documented these UX/a11y insights in `.Jules/palette.md`.
2026-06-18 ⚡ Bolt: Reuse HTTP connections with requests.Session() in export_offline.py
    💡 What: Replaced individual `requests.get()` calls with a shared `requests.Session()` object in the offline presentation exporter script.
    🎯 Why: Downloading multiple external assets (like Google Fonts and FontAwesome CSS, and their nested `@import` resources) from the same domain requires negotiating a new TCP connection and TLS handshake for every single asset. Connection pooling via Keep-Alive drastically cuts this network overhead.
    📊 Impact: Expected to significantly reduce the execution time of generating the offline HTML presentation deck by decreasing network latency on asset downloads.
    🔬 Measurem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
2026-08-25 Add ESP32-H2 firmware for Induction Heating Prototype
    - Create firmware directory under Project Files/Induction Heating Prototype/Firmware/
    - Configure dual induction heater control (GPIO4 Main Coil SSR 1, GPIO5 Catalytic Converter SSR 2)
    - Recalibrate pressure sensor for 0-15 PSI range and scale threshold parameters
    - Add pump control on GPIO11 behind feature flag
    - Update CMake and build scripts for induction firmware project
2026-08-25 Add Induction Heating Firmware & Enhance Dryness Monitoring
    - Create dedicated ESP32-H2 firmware variant for Dual Induction Heating Prototype under Project Files/Induction Heating Prototype/Firmware/
    - Configure dual induction heater drivers (GPIO4 Main Coil SSR 1, GPIO5 Catalytic Converter SSR 2)
    - Recalibrate pressure sensor mapping and threshold parameters for 0-15 PSI (0-5V) range
    - Add pump control driver on GPIO11 behind feature flag
    - Enhance dryness_monitor.py with EMA noise filtering and temperature slope thresholding for low-moisture samples
    - Update PCB pin mapping documentation, add Induction Prototype README, and document PCB v0.4.0 hardware revision plan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
    [dryness_monitor.py, test_dryness_monitor.py]
2026-08-25 Add Induction Heating Firmware & Enhance Dryness Monitoring Documentation
    - Add comprehensive docstrings and module documentation to test_dryness_monitor.py and dryness_monitor.py
    - Update PCB pin mappi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
    [test_dryness_monitor.py]
2026-08-25 Add Induction Firmware, Split BOM Specs, and Update Documentation
    - Split BOM and peripheral hardware documentation in Control Board.md for Conductive vs Induction variants while preserving all original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
2026-08-26 Add Induction Firmware, Safety Logic, Heater Controller & Presentation Slides
    - Implement emergency overpressure (>14.0 PSI) and overtemp (>250.0°C) hardware safety interlocks in main.c and valve_controller.py
    - Implement HeaterController class in heater_controller.py with PWM time-windowing, hysteresis, and safet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
    [Frame for Assembly_v2.1.FCStd, Frame for Assembly_v2.2.FCStd, Frame for Assembly_v2.FCStd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]
2026-08-26 Add Induction Heating Firmware, Safety Interlocks & Control Modules
    - Implement HeaterController class in heater_controller.py with PWM time-windowing, hysteresis, and safety cutoffs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
    [Frame for Assembly_v2.0.FCStd, Frame for Assembly_v2.1.FCStd, Frame for Assembly_v2.2.FCStd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]
2026-08-26 Add Dual Induction Firmware, Safety Interlocks & Document Updates
    - Create dedicated ESP32-H2 firmware for Dual Induction Heating Prototype under Project Files/Induction Heating Prototype/Firmware/
    - Implement HeaterController class in heater_controller.py with PWM time-windowing, hysteresis, and safety cutoffs
    - Enhance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
2026-08-26 Restore documentation comments and header notes in main.c
    - Restore MAX31855 SPI frame structure docstrings and hardware pin notes in main.c
    - Ensure full alignment of comments and driver configuration notes
2026-08-28 Add GPIO12 flush button and 30-min cycle timeout to induction firmware
2026-08-28 Add flush button, WS2812 RGB LED status, and 30-min cycle timeout to ESP32-H2 firmware
2026-08-28 Add flush button, led_strip WS2812 status, and 30-min cycle timeout to ESP32-H2 firmware
2026-08-28 Add flush button, WS2812 RGB LED status, and 30-min timeout to ESP32-H2 firmware
2026-08-28 Add flush button, WS2812 LED status, 30-min timeout, and build script flash/monitor options
2026-08-28 Add flush button, WS2812 status LED, 30-min timeout, and v1.2 chip revision support
2026-08-28 Add flush button, WS2812 status LED, 30-min timeout, and ESP32-H2 v1.2 chip revision support
2026-08-28 Add flush button, WS2812 status LED, 30-min timeout, and v1.2 chip rev support
2026-08-28 Add flush button, WS2812 LED status, 30-min timeout, and v1.2 chip rev support
2026-08-29 fix(firmware): update ESP-IDF build scripts and sdkconfig defaults
    - Remove deprecated Kconfig symbols from sdkconfig.defaults in both Induction and Conductive prototype directories.
    - Add submodule update recursive flags to build_firmware.sh and build_firmware.bat to resolve mbedtls submodule header mismatches during ESP-IDF toolchain updates.
2026-09-15 feat: Implement logarithmic pressure release and pyrolysis mapper tool
    - Redesigned `valve_controller.py` to use a time-proportional PWM simulation that releases pressure on a logarithmic decay curve.
    - Added a hard minimum seal pressure floor (`min_seal_pressure=4.0`) to immediately close the valve and preserve gasket integrity when pressure drops too low.
    - Ensured the valve only enters the release phase when *both* `TARGET_PRESSURE` (15.0) and `TARGET_TEMP_C` (121.0) are reached.
    - Propagated identical time-proportional control and safety floor logic into both C firmware targets (`Induction Heating Prototype/Firmware/main/main.c` and `Conductive Heating Prototype/Firmware/main/main.c`).
    -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
    [main.c, pyrolysis_mapper.py, test_valve_controller.py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]
2026-09-16 feat: Implement logarithmic pressure release and pyrolysis mapper tool
    - Ensured the valve only enters the release phase when *both* `TARGET_PRESSURE` (8.0) and `TARGET_TEMP_C` (121.0) are reached.
    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
    [main.c, test_valve_controller.py, valve_controller.py]
2026-09-21 Implement robust state machine and safety interlocks for heater control
    Adds SystemController to manage high-level run states (OFF, HEATING, COOLING, ERROR).
    Implements critical safety checks:
    1. Negative Pressure Failure: trips ERROR if pressure < -0.2 PSI for >2 cycles.
    2. Unintended Temperature Rise: detects runaway BJT failure (cumulative >=5C rise in OFF/COOLING after 60s grace, or absolute >=50C rise anytime while OFF).
    3. Heater Stagnation: trips ERROR if temp rise < 3C over rolling 180s window while HEATING.
    State transitions default to safe actuator positions on fault. Unit tests verify all behaviors.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
2026-09-21 Fix C firmware state machine and thermal runaway safety interlocks
    - Implemented `STATE_OFF`, `STATE_HEATING`, `STATE_COOLING`, `STATE_ERROR` enums in both prototype `main.c` files.
    - Added negative pressure detection (triggering `< -0.2 PSI`) which explicitly opens the vent valve in `STATE_ERROR`.
    - Added Unintended Temperature Rise fault: latches if temperature rises by `5C` after a `60s` grace period in `OFF` or `COOLING` states. Absolute `50C` increases trigger immediately.
    - Added Stagnation loop: uses a ring buffer over `180s` rate-limited to 1hz to detect if the heater is producing `< 3.0C` rise.
    - Handled state transitions, status LEDs mapping, and graceful fallback for both inductiv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
    [main.c]
2026-09-24 Update ADC calibration values for pressure sensor
    To shift the pressure output by exactly +10.68 PSI, you need to convert that pressure value into raw ADC ticks and subtract it from your current baseline.
    * **Current Scale:** $\frac{3008 - 320}{100\text{ PSI}} = 26.88\text{ ADC ticks per PSI}$
    * **Offset in Ticks:** $10.68\text{ PSI} \times 26.88 = 287.08\text{ ticks}$
    * **New ADC_ZERO:** $320 - 287 = 33$
    Update your code to:
    ```c
    #define ADC_ZERO 33.0f // Adjusted from 320.0f for +10.68 PSI offset
    ```
    **Keeping the Calibration Slope Accurate**
    If the sensor has a fixed baseline offset (which is standard for environmental shifts), shifting only `ADC_ZERO` will slig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
    [main.c]
2026-09-24 Disable pressure-based auto cycle start
    Commented out pressure-based auto cycle start logic.
2026-09-24 Update heater control logic and cycle management
2026-09-24 feat: Refactor logarithmic valve control to single-shot with cooldown
    - Replaces high-frequency time-proportional PWM on the solenoid valve with a calculated burst duration and mandatory 2000ms cooldown.
    - Prevents solenoid "hammering" while maintaining proportional response.
    - Updates python logic in `valve_controller.py`, adds complete test coverage in `test_valve_controller.py` including threshold testing.
    - Updates C firmware logic for both Induction and Conductive Heating prototypes in `main.c`.
    [main.c, test_valve_controller.py, valve_controller.py]
2026-09-24 Modify heater control logic for cycle management
2026-09-24 Update ADC calibration values for pressure measurement
2026-09-24 fix: improve firmware error state logging and increase runaway standoff
    - Added an explicit `ESP_LOGE` message to the `transition_to` function when entering `STATE_ERROR` to inform the serial output that the heaters are disabled and the valve is forced open.
    - Increased the stuck BJT runaway detection grace period (cooling standoff) from 60 seconds to 1 hour (3600000 ms) in both the Induction and Conductive firmware prototypes to account for the thermal mass of the 12L system.
    - Increased the heater stagnation detection window from 3 minutes to 1 hour, adjusting the history recording rate limits from 1s to 20s to fit the array size.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
    [main.c]
2026-09-25 feat: Implement dynamic target pressure timeout logic for dryness detection
    - Replaces static `has_pressurized` boolean with dynamic target pressure timeout.
    - Starts a 5-minute timer when temperature is >= 100C and pressure is below target.
    - If timeout is reached, drops the target pressure by 1.0 PSI (down to the 4.0 PSI seal pressure floor).
    - Latches the system into the `DRY` state if it times out while attempting to reach the 4.0 PSI floor.
    - Extends tests in `test_valve_controller.py` to cover target pressure dropping, dynamic vent bounds, and dry latching behavior.
    - Applies to python scripts and both prototype C firmwares.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
    [main.c, test_valve_controller.py, valve_controller.py]
2026-11-01 docs: archive active session memories to .jules/memory.md
    - Created and appended to `.jules/memory.md`.
    - Grouped memories under current date (`## Archived: YYYY-MM-DD`).
    - Formatted output as clean Markdown bullet points.
    - Kept file append-only without modifying other project files.
2026-11-11 feat: add cycle orchestrator and harden telemetry processing
    - Implement CycleOrchestrator state machine (IDLE, HEATING, CHARRING, COOLING, ERROR) coordinating heater, valve, and dryness monitor.
    - Implement hardware-mirrored safety interlocks: negative pressure tripping, absolute/stuck thermal runaway detection, and thermal stagnation checks.
    - Harden pyrolysis_mapper with robust CLI argument parsing via argparse and offline file/replay capabilities.
    - Enhance sensor fault tolerance for None/NaN readings and negative pressure counting in heater_controller and valve_controller.
    - Expand unit test coverage across all new and updated components.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
